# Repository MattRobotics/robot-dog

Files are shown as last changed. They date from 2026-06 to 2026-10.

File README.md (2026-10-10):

# MATDOG — Custom Quadruped Robot

MATDOG is Matt Robotics' custom quadruped platform: a 17-DOF mechanical design with an
articulated head, an ESP32-S3 real-time controller, and a future Jetson-based high-level stack.
This repository is the single active engineering repository for the robot.

> **⚠ FLASH SAFETY NOTICE — 2026-10-08, updated for PR-3. DO NOT FLASH MAIN: do not use `main`
> to update the current robot.**
>
> - `main` carries Calibration Persistence V1, the flash layout `MATDOG_16M_2x5M_NVS_V1` (PR-1),
>   a selective part of the dev.1 line (PR-2) and, since PR-3, the dev.2/dev.3 source delta. Its
>   firmware identity is `0.2.0-dev.3`. `scripts/build.sh` uses `PartitionScheme=custom` and
>   `scripts/upload.sh` refuses every full-image upload.
> - Since 2026-10-10, `main` also has the exact two LED source file blobs of the physically
>   validated, **separate** LED-only firmware `fee9383` (`LED_TRANSPORT=RMT_DMA`); that firmware now
>   runs on the robot. A build of `main` is **not** the installed binary: Git provenance and build
>   ID differ. No flash or motion is authorized.
> - Historical dev.3 Hardware Validation (2026-10-07): execution COMPLETE, acceptance BLOCKED.
>   The later LED-only validation (2026-10-10) passed in its limited scope; **no general release
>   or motion acceptance** is granted.
> - These integrations are **not** a flash authorization and **not** a hardware acceptance. No
>   `main` build has been accepted on hardware.
> - `MOTION_AUTHORIZED=0`, `RESTORE=NOT_IMPLEMENTED`. Nothing here authorizes a flash, a migration
>   or any motion.
>
> Details and sources: [`FLASH_LAYOUT_SAFETY_NOTICE.md`](05_Firmware/MATDOG_Controller/FLASH_LAYOUT_SAFETY_NOTICE.md).
> The quoted snapshot below is the historical state of `main` on 2026-10-01 and has not been
> updated. Elsewhere in this file only the statements on Persistence V1, Wi-Fi/OTA, the motion
> library, the boot census, the thermal verdict and the build identity were updated; a full status
> synchronization is a separate change.

### What is on `main` (after PR-3)

| Layer | Content |
|---|---|
| Code integrated | Persistence V1 and layout V1; post-abort recovery; guarded release stages with DALY supervision; startup RF recovery; Wi-Fi/OTA V3 (TLS, OTA ingest compiled out by default); charging presentation priority; **dev.2 read-only boot servo census**; **dev.3 thermal verdict from direct reads only** and the host runner's one-shot post-abort recovery; identity `0.2.0-dev.3`; pure motion library G1–G5-A, **unwired** (no path to the servo bus) |
| Offline tests | static audit and C++/Python host suites, USB_ONLY and ROBOT_POWERED builds: see [`VALIDATION.md`](05_Firmware/MATDOG_Controller/VALIDATION.md), section PR-3 |
| Hardware results (historical, of the dev.2/dev.3 candidate, not of a `main` build) | 2026-10-06: boot census 13/13; fresh Q0 and calibration 24/24 under dev.3; SAVE/ACK and LOAD across a reset (no real power cycle); the automatic post-abort recovery did not run. Records: [dev.2 audit](09_Logs/Validation_Reports/MATDOG_V0_2_DEV2_BOOT_SELFTEST_DELTA_AUDIT_2026-10-06.md), [dev.3 audit](09_Logs/Validation_Reports/MATDOG_V0_2_DEV3_THERMAL_DELTA_AUDIT_2026-10-06.md). The 2026-10-07 report is not in the repository |
| LED-only hardware validation (2026-10-10) | RMT DMA active on installed `fee9383`; 10-minute ring observation with SoftAP enabled and 0 anomalies; no motor activity ([report](09_Logs/Validation_Reports/MATDOG_LED_RMT_DMA_DIRTY_FRAME_HW_VALIDATION_2026-10-10.md)) |
| Hardware acceptance / release acceptance | LED-only hardware check PASS under tested conditions; dev.3 overall acceptance BLOCKED; no `main` build accepted and no general release approved |
| Deferred | motion execution suites, fresh oracles and the G35/G4/G4.1/G5-A evidence; 38 third-party XGO extracts and XGO-derived data are **not reachable from `main`**; the historical GitHub branches that held them have been deleted, the original commits are in a non-public archive, and removal of previously published blobs from GitHub storage, caches and clones cannot be guaranteed ([ADR-004](09_Logs/Architecture_Decisions/ADR-004_Third-Party_Reverse_Engineering_Material_Boundary.md)) |

> **Historical snapshot — 2026-10-01 (PR #35 merged)**
>
> - **Installed population:** 13 ST3215 (12 leg joints plus neck ID 51); 17 canonical slots,
>   with IDs 52–55 intentionally absent.
> - **Frozen release:** `matdog-controller-v0.1.0`; the separately hardware-validated development
>   firmware is `dfcecb670d05`, `ROBOT_POWERED`.
> - **TRUE Full Calibration HARDWARE-VALIDATED, 2026-10-01:** LF/RF/RH/LH each passed 6/6,
>   all **24/24 contacts** accepted, fine-pass repeatability <= 4 ticks, SAFE_OFF 13/13.
> - **Calibration is RAM-only.** Evidence is exported and backed up; boot-time restoration is
>   not implemented. Operational envelopes are not approved and stand/gait are not authorized.
> - The gait engine remained offline on 2026-10-01. Since PR-2 the pure motion library is on
>   `main`, unwired; its execution suites are deferred.
>
> [2026-10-01 full hardware report](09_Logs/Validation_Reports/Full_Calibration_24_Contact_Hardware_2026-10-01/README.md).

| Track | State |
|---|---|
| `ROBOT_POWERED` no-motion baseline | **VALIDATED** |
| TRUE Full Calibration software and hardware | **24/24 HARDWARE-VALIDATED — 2026-10-01** |
| Calibration Persistence V1 | **IMPLEMENTED on `main` (PR-1, 2026-10-08)** — offline/host-tested; RESTORE not implemented; no hardware acceptance |
| Operational envelopes / JointLimits | **BLOCKED** — not approved |
| Telemetry integrity, LOWER MAX margins, q0 refinement | **OPEN follow-ups** |
| Gait engine | **IN PROGRESS** — pure library on `main` (PR-2), unwired; execution suites and evidence DEFERRED |
| Stand / gait hardware | **BLOCKED** |

The step-by-step route, and what blocks what, is in [`ROADMAP.md`](01_Docs/02_Architecture/ROADMAP.md);
the calibration state in detail is under *Calibration on `main`* below.

## Status vocabulary

Every current-facing document uses these meanings:

| Label | Meaning |
|---|---|
| **VALIDATED** | Implemented and exercised within a stated real-hardware scope. |
| **IMPLEMENTED** | Present in code or hardware, but not yet fully exercised in the relevant hardware scope. |
| **DECIDED** | An approved architecture or policy; implementation may be partial or absent. |
| **TO_TEST** | Implemented or assembled enough for a defined validation step that has not yet passed. |
| **TO_DESIGN** | Direction is known, but the detailed design is not frozen. |
| **FROZEN** | Immutable release, tool, or evidence baseline. |
| **SUPERSEDED** | Replaced as current truth; retained only for traceability. |
| **HISTORICAL** | Accurate evidence of an earlier state, never current authorization. |

## Project status

### VALIDATED

- The 17 allocated ST3215 units completed bench QC/provisioning and hold the frozen
  `MATDOG_C018_V1` persistent profile. This proves the bench campaign, not present installation.
- MATDOG Controller V0.1 boot, native USB CDC, live BNO085 acquisition, viewer-compatible output,
  expected-offline classification, and concurrent soak passed on the real ESP32-S3 under the
  `USB_ONLY` profile.
- Direct ESP32-S3 ownership of the ST3215 bus was demonstrated by the frozen bench tools.
- `ROBOT_POWERED` no-motion operation on the real robot (G3 formal PASS and G3.1 PASS,
  2026-09-18): the hardware profile, the servo population model (canonical 17 / expected-now 13 /
  absent-by-design 52-55) and structured census, live read-only DALY, live LED, two identical
  censuses, `SAFE_OFF` `VERIFIED_OFF` and `torque=0` on all 13, and a Controller loop independent
  of USB CDC host presence. That validation applies to the firmware of that date. The dedicated bounded-calibration
  path subsequently passed its own 24-contact hardware gate on 2026-10-01; operational motion
  has not been validated.
- The post-rewire power gate (2026-09-24): the historical `B-`/`P-` bypass is corrected, and
  physical KEY OFF now measures 0 V on every protected rail with no charger and no USB present.
- LED Status Manager V2 (2026-09-26, source `88062e1`) and the read-only q0 capture on the real
  robot (CR2-C, 2026-09-27, build `315d4ade6ff0`): 12/12 joints, nine samples per joint, Torque
  OFF, maximum spread 0 ticks. It proves the capture path, not calibration.
- The external USB service/programming port (2026-09-24): GPIO19/GPIO20/GND, no host VBUS —
  enumeration, bidirectional CDC and the `esptool` reset/flash-identification handshake all
  confirmed with the onboard USB-C disconnected.
- Manual charging, common-port electrical behaviour (2026-09-22/23 + 2026-09-24): a connected
  charger backfeeds the `B+`/`P-` load bus directly, independent of KEY/Discharge-MOS state. Full
  charging/dock qualification remains **FUTURE**.

- Bounded four-leg calibration passed on hardware on 2026-10-01 (firmware `dfcecb6`):
  24/24 contacts and SAFE_OFF 13/13. This does not validate operational motion.

### IMPLEMENTED

- One modular Controller image contains ServoBus diagnostics, BNO085 acquisition, read-only DALY
  telemetry, LED-ring control, USB diagnostics, health aggregation, and a power-state baseline.
- Wi-Fi/OTA core is implemented and offline-tested; the relevant hardware gates remain open.
- `ActuatorAuthority`, the Safe Actuator policy and the four-leg Full Calibration engine are
  integrated. Only the bounded calibration write path has been hardware-validated; service/QC
  writes and operational stand/gait have not been validated.
- Calibration Persistence V1 (record, A/B store in the dedicated `matdog_nvs` partition,
  SAVE/ACK/RECONCILE, boot LOAD) and the flash layout `MATDOG_16M_2x5M_NVS_V1` are on `main`
  since PR-1 (2026-10-08), offline/host-tested. LOAD never restores a calibration into the
  motion path (`RESTORE` not implemented). Approved operational envelopes are not implemented.

### DECIDED

- MATDOG will use one permanent Controller firmware, extended by reviewed modules rather than
  replaced by separate operational sketches.
- The ESP32-S3 is the sole operational ST3215 bus owner. The high-level host sends semantic intent,
  never raw bus traffic in normal operation.
- Normal future updates will use Wi-Fi/OTA. Native USB CDC/USB-C remains the permanent wired
  service and recovery path.
- GPIO19/GPIO20 mean native USB D-/D+; their historical Jetson-UART use is **SUPERSEDED**.
- The ESP32-S3 is powered from the DALY-protected B+/P− domain through the 5 V step-down. The
  bistable logo pushbutton connects directly to DALY `KEY`; no ESP32 KEY GPIO is required. Its
  function is now a **VALIDATED** power-off (2026-09-24, no charger/USB present) — the fused
  disconnect remains the trusted isolation whenever a charger may be connected, because a
  connected charger backfeeds the load bus independent of KEY state (see *Where we are* below).

### TO_TEST

- Telemetry integrity following 23 isolated temperature outliers and 39 diagnostic held-speed
  transients in the successful hardware run (no confirmed thermal fault or held-role failure).
- LOWER MAX shortfall and reduced repeat-calibration scout margins, particularly RF (+6 ticks)
  and LH (+13 ticks); separate reviewed resolution, no unilateral corridor change.
- BMS KEY configuration persistence across a true DALY power cycle.
- Charging/dock qualification beyond the attended manual session.

### TO_DESIGN

- The host command/telemetry protocol carried over USB CDC.
- Calibration restore across reboot (`RESTORE`), the operational stand/gait workspace with its
  joint limits and margins, and the integrated maintenance, service, Servo QC and provisioning
  workflows.
- Stand and gait motion on hardware, stabilization, ROS 2/MoveIt 2, and complete Jetson
  integration. The pure motion library is on `main` since PR-2 but unwired and not operational;
  its execution suites and evidence are deferred.

### FROZEN, SUPERSEDED, and HISTORICAL

- **FROZEN:** the official Controller tag and the three ST3215 bench tools: Bench QC V6.1, Source
  Signature Survey V1, and Provisioner V6.
- **SUPERSEDED:** mandatory NormaCore Station bus ownership, GPIO19/20 Jetson UART, and Generic V25
  as the current development milestone.
- **HISTORICAL:** dated calibration reports, Geometry/Phase 2A records, old handoffs, and previous
  Station-mediated evidence. They remain preserved and do not describe today's robot.

## Physical hardware today

The allocation registry and the installed population answer different questions:

| Fact | Current value | Canonical source |
|---|---:|---|
| Allocated unit/joint/bus-ID slots | **17** | [`MATDOG_SERVO_ALLOCATION.yaml`](06_Software/Matdog_Core/config/MATDOG_SERVO_ALLOCATION.yaml) |
| Physically installed servos | **13** | This current project snapshot |
| Installed population | 12 leg servos + `NECK_ROTATION` ID 51 | This current project snapshot |
| Allocated but intentionally absent | 52 `NECK_PITCH`, 53 `HEAD_ROTATION`, 54 `HEAD_PITCH`, 55 `JAW` | Allocation registry + this snapshot |

Do not reduce the 17-unit registry to match the current 13-unit build. Allocation is a design/ID
contract; installation is physical state.

```text
ASUS Ubuntu development host / future Jetson Orin Nano Super
    -> native USB 2.0 Full-Speed / USB CDC
MATDOG Controller on ESP32-S3
    -> UART: GPIO17 TX, GPIO18 RX, shared GND
Seeed Bus Servo Driver
    -> Feetech serial bus, 1 Mbps
13 physically installed ST3215 servos
    = 12 legs + NECK_ROTATION ID51
```

All 17 allocated units were bench-provisioned with `PositionOffset = 0`, a servo-level
fact distinct from joint calibration. The current installation passed TRUE Full Calibration
24/24 on 2026-10-01. The 12 fresh q0 values, contacts and diagnostics were exported and
archived. In that session they were RAM-only in the Controller: no automatic restore exists, no
motion is thereby authorized, and no servo EEPROM, ID, `PositionOffset` or NVS write occurred.
Since PR-1 an NVS record store (Calibration Persistence V1) is IMPLEMENTED on `main`. SAVE/ACK and
LOAD across a reset were observed on the dev.3 candidate on 2026-10-06; a real power cycle was not
shown. The runtime state is still held in RAM, automatic `RESTORE` is NOT_IMPLEMENTED, and hardware
acceptance is BLOCKED (dev.3: execution COMPLETE, acceptance BLOCKED).

## Official firmware baseline

| Item | Value |
|---|---|
| Frozen release | `matdog-controller-v0.1.0` |
| Tagged repository commit | `c54862f38a9cbd5e46d6b1770a6d109cc99b5c02` |
| V0.1 USB_ONLY hardware-validated source | `5b371da5482f9b0bd2df1c37ed361250ea54ae8f` |
| Latest hardware-validated development firmware (scope: 2026-10-01 Full Calibration) | `dfcecb670d0565d2db1a8152b6cd7ad230bdb87d` (`ROBOT_POWERED`) |
| Installed candidate (2026-10-06/07) | `0.2.0-dev.3`, provenance `b3fd945bdaf37d192d97b605ac0f59b67f1dba45`; execution COMPLETE, acceptance **BLOCKED**; not an accepted release |
| Full Calibration merge commit on main | `1fd0f5afc3cc737d1ac82183b4ce204dcd01c402` (PR #35; documentation included) |
| Hardware report | [hardware-validation report](09_Logs/Validation_Reports/Full_Calibration_24_Contact_Hardware_2026-10-01/README.md) |

The frozen release, the hardware-flashed source and the later Git merge commit are distinct
identities. The merge commit itself was not flashed.

## Where we are, and the next gate

```text
COMPLETE   Controller V0.1 baseline              VALIDATED (USB_ONLY hardware)
COMPLETE   G2 ROBOT_POWERED software             PASS / FROZEN
COMPLETE   G3 ROBOT_POWERED no-motion            PASS (formal, 2026-09-18)
COMPLETE   G3.1 CDC-independent Controller loop  PASS (2026-09-18)
COMPLETE   DALY KEY research                     COMPLETE (read-only, 2026-09-19)
COMPLETE   DALY 0x81 read                        LIVE VERIFIED (read-only, 2026-09-19)
COMPLETE   DALY KEY write (0x0120 := 0x005A)     LIVE VERIFIED (2026-09-19; ACK + read-back)
                                                 current KEY logic = DISCHARGE (0x005A)
COMPLETE   B-/P- hardware bypass correction      VERIFIED (2026-09-24; TECNOIOT VIN- now on P-)
COMPLETE   post-rewire power gate A-E            PASS (2026-09-24; dead-circuit + KEY OFF/ON +
                                                 powered no-motion regression, live)
COMPLETE   external USB service/programming port VALIDATED (2026-09-24; GPIO19/20, no host VBUS —
                                                 enumeration, CDC, esptool reset/flash-ID)

OPEN       manual charging common-port behaviour VERIFIED electrically (2026-09-22/23 + 09-24):
                                                 a connected charger backfeeds B+/P- regardless
                                                 of KEY state
OPEN       autonomous dock/charging              OPEN — no dock hardware evidence beyond one
                                                 attended manual charging session

COMPLETE   read-only q0 capture              VALIDATED (CR2-C, 2026-09-27)
SUPERSEDED UPPER-only 8-contact milestone      Historical scope error
COMPLETE   TRUE 24-contact calibration         HARDWARE PASS (2026-10-01, PR #35)
CURRENT    Calibration Persistence V1          IMPLEMENTED on main (PR-1); RESTORE not
                                                 implemented; no hardware acceptance
OPEN       Telemetry, LOWER MAX, zero review   Before hardware locomotion
THEN       Operational envelopes / JointLimits BLOCKED pending approval
THEN       Stand / gait hardware               BLOCKED
```

Power domains, KEY semantics, every power state and the charging gates are owned by
[`04_Electronics/MATDOG_POWER_STATES_AND_CHARGING.md`](04_Electronics/MATDOG_POWER_STATES_AND_CHARGING.md).

`ROBOT_POWERED` is **VALIDATED for no-motion operation**: DALY live read-only, LED live, 13/13
expected servos present with 4 absent by design in two identical censuses, `SAFE_OFF`
`VERIFIED_OFF` and `torque=0` on all 13. The Controller loop is independent of USB CDC host
presence: BNO085 acquisition runs at 50.1 Hz with the port closed (G3.1). No commanded servo motion occurred and no robot motion was observed during validation.

### Calibration on `main`

- **Validated scope:** LF V25-derived full-leg state machine, generalized to four legs and 24
  physical contacts (HIP/UPPER/LOWER, MIN/MAX), `HARDWARE_CONTACT_CALIBRATED` 6/6 per leg.
- **Hardware session:** 2026-10-01, firmware `dfcecb6`, `ROBOT_POWERED`, 24/24 witnesses
  accepted on the first attempt and SAFE_OFF 13/13 verified. [hardware-validation report](09_Logs/Validation_Reports/Full_Calibration_24_Contact_Hardware_2026-10-01/README.md).
- **Authority:** session-scoped permits, promoted fresh q0 and the Safe Actuator layer govern
  all bounded calibration writes. No operational actuator authority is implied.
- **Persistence:** in the 2026-10-01 session the promoted calibration was RAM-only and the
  exported data is not an implemented restore. Since PR-1 `main` contains Calibration
  Persistence V1 (SAVE/ACK/LOAD); `RESTORE` is still not implemented.
- **Operational envelope:** not approved (`parameters_approved=0`, `envelope_accepted=0`);
  no stand or gait hardware motion is authorized.
- **Persistence status on `main` (PR-1):**
  - Calibration Persistence V1 **IMPLEMENTED**: SAVE/ACK/RECONCILE and boot LOAD,
    offline/host-tested.
  - `RESTORE` **NOT_IMPLEMENTED**.
  - **No hardware acceptance** for any `main` build.
  - A real power cycle of the persistence path is **not validated**.
- **Follow-ups:** persistence hardware acceptance (including a real power cycle) and
  `RESTORE`; telemetry integrity; LOWER MAX scout margin;
  reviewed mechanical-zero refinement; operational workspace and limits.

### Open hardware notes

- **DALY `KEY` — RESOLVED as a power-off, 2026-09-24.** Research (2026-09-19): no public DALY
  document publishes a K-series KEY register; DALY's own BMSTool V1.14.79 (static inspection)
  points to KEY logic at `0x0120` on a second Modbus personality (`0x81`). Live-verified read-only
  the same day with `@BMS KEY READ`: the unit's KEY logic was **DISABLED (`0x0055`)**
  pre-commissioning, consistent with the G3 finding, where toggling the physical KEY produced no
  observed change in `discharge_mos`. The single guarded write (`@BMS KEY SET DISCHARGE CONFIRM`,
  `0x0120 := 0x005A`) was sent **once, live, on 2026-09-19** and read back as `0x005A`
  (DISCHARGE). The follow-on physical KEY test was inconclusive at the time: a hardware `B-`/`P-`
  bypass (TECNOIOT `VIN-` on raw `B-`) kept the load rail powered with the discharge MOS open. That
  rewire is now **complete**, and the post-rewire power gate A–E **passed live on 2026-09-24**:
  with no charger and no USB present, KEY OFF measures 0 V on every protected rail. A connected
  charger still backfeeds the `B+`/`P-` bus independent of KEY state, so the fused disconnect
  remains the trusted physical isolation method whenever a charger may be present.
- **GPIO19/GPIO20 — VALIDATED 2026-09-24.** GPIO19 = native USB D−, GPIO20 = native USB D+. The
  external 19/20/GND connector (host VBUS intentionally not wired) was validated as a
  service/programming port: native enumeration, bidirectional CDC and the `esptool`
  reset/flash-identification handshake all confirmed with the onboard USB-C disconnected. It does
  not power the ESP32 on its own.

Criteria are owned by the Controller
[`DEVELOPMENT_GATES.md`](05_Firmware/MATDOG_Controller/DEVELOPMENT_GATES.md); evidence by the
Controller [`VALIDATION.md`](05_Firmware/MATDOG_Controller/VALIDATION.md).

### Everything after that

The full development sequence, its hard dependencies and what is blocked by what are owned by
[`ROADMAP.md`](01_Docs/02_Architecture/ROADMAP.md). Per-gate entry conditions and pass/fail
criteria are owned by
[`DEVELOPMENT_GATES.md`](05_Firmware/MATDOG_Controller/DEVELOPMENT_GATES.md). They are
deliberately not duplicated here.

## Target architecture

The permanent MATDOG Controller is the integration point for future Diagnostics, Maintenance,
Service, Servo QC, Provisioning, Full Leg Calibration, Wi-Fi/OTA, and host transport. Calibration
motion is implemented behind the Safe Actuator layer; stand, IK, gait, and stabilization come
later, behind explicit safety and calibration gates.

**DECIDED (2026-09-16):** MATDOG will also host a permanent **Embedded Web UI / Control & Service
Dashboard** served by the ESP32-S3 and reached from a phone, tablet, the ASUS or a future Jetson.
It is a staged, safety-gated target and none of it exists in firmware yet. Every browser command
must travel `Browser -> CommandRouter -> Controller services -> authority -> Safe Actuator ->
ServoBus`; a direct browser-to-`ServoBus` path is permanently forbidden. Contract in
[`ARCHITECTURE.md`](01_Docs/02_Architecture/ARCHITECTURE.md#embedded-matdog-web-ui--control--service-dashboard).

The Full Leg Calibrator V1 tree is a preserved oracle/evidence source, held by the annotated tag
`archive/2026-08-29/full-leg-calibrator-v1-h0` -> `15f3fb8f378e6cadf6bc479bfcaca2947741c9fd` (the
former branch `matdog/full-leg-calibrator-v1` was archived 2026-09-18 and no longer exists). Its
useful calibration engine, safety, and evidence patterns may later be migrated selectively into
the Controller; it is not the final runtime architecture and must not be merged wholesale.

The frozen ST3215 tools remain immutable qualification evidence even after equivalent service
capabilities are integrated into the Controller.

## Canonical documentation

| Question | Canonical owner |
|---|---|
| What exists and what happens next? | This `README.md` |
| What are the architecture contracts and target direction? | [`ARCHITECTURE.md`](01_Docs/02_Architecture/ARCHITECTURE.md) |
| What is the development sequence, and what blocks what? | [`ROADMAP.md`](01_Docs/02_Architecture/ROADMAP.md) |
| What must be true before a stage may begin? | [`DEVELOPMENT_GATES.md`](05_Firmware/MATDOG_Controller/DEVELOPMENT_GATES.md) |
| How are power, wiring, and connectors implemented? | [`04_Electronics/README.md`](04_Electronics/README.md) |
| What firmware exists? | [`05_Firmware/README.md`](05_Firmware/README.md) |
| May `main` be flashed on the current robot? | [`FLASH_LAYOUT_SAFETY_NOTICE.md`](05_Firmware/MATDOG_Controller/FLASH_LAYOUT_SAFETY_NOTICE.md) — **no** |
| What is the Controller baseline and service model? | [Controller README](05_Firmware/MATDOG_Controller/README.md) |
| What Controller behavior was actually validated? | [Controller validation](05_Firmware/MATDOG_Controller/VALIDATION.md) |
| Which 17 units/joints/IDs are allocated? | [`MATDOG_SERVO_ALLOCATION.yaml`](06_Software/Matdog_Core/config/MATDOG_SERVO_ALLOCATION.yaml) |
| Is calibration commandable? | [`MATDOG_JOINT_CALIBRATION.yaml`](06_Software/Matdog_Core/calibration/MATDOG_JOINT_CALIBRATION.yaml) |
| Where is frozen ST3215 evidence? | [`ST3215_EVIDENCE_INDEX.md`](09_Logs/ST3215_EVIDENCE_INDEX.md) |
| Where is superseded/historical material? | [`09_Logs/Historical/`](09_Logs/Historical/README.md) |
| How did the project get here (June–October 2026)? | [`HISTORY_INDEX.md`](09_Logs/HISTORY_INDEX.md) |
| Which decisions were taken, and which are superseded? | [ADR index](09_Logs/Architecture_Decisions/README.md) |
| Which development logs and validation reports exist? | [Development Log index](09_Logs/Development_Log/README.md), [Validation Reports index](09_Logs/Validation_Reports/README.md) |
| What is still open or missing? | [`OPEN_ITEMS.md`](09_Logs/OPEN_ITEMS.md) |
| Where do original commit SHAs map after the selective integrations? | [`COMMIT_PROVENANCE_MAP.md`](09_Logs/COMMIT_PROVENANCE_MAP.md); archives held outside GitHub: [`EXTERNAL_ARCHIVES.md`](09_Logs/EXTERNAL_ARCHIVES.md) |
| Where is Geometry Compiler verification evidence? | [`REPOSITORY_VERIFICATION_INDEX.md`](REPOSITORY_VERIFICATION_INDEX.md) (**HISTORICAL/REFERENCE**, not project status) |

## Repository layout

```text
01_Docs/        architecture and stable technical references
02_BOM/         components, suppliers, and costs
03_CAD/         CAD, URDF, meshes, and mechanical exports
04_Electronics/ wiring, power, and servo-mapping references
05_Firmware/    permanent Controller plus frozen bench tools
06_Software/    calibration, geometry, kinematics, and host-side software
07_Media/       images, renders, and videos
08_Tests/       repeatable validation procedures
09_Logs/        evidence, decisions, reports, and historical archives (start at HISTORY_INDEX.md)
09_Backups/     manifests and receipts of encrypted flash backups (no plaintext images)
```

## Safety boundary

- No motion from stale or un-restored calibration. The 2026-10-01 contact validation
  does not authorize stand, gait or load-bearing operation. Any new hardware calibration
  or motion session requires separate operator authorization.
- No servo EEPROM/ID change or hardware reflash is authorized by this documentation. In
  particular, never flash a `main` build onto the current robot (see the flash safety notice
  at the top of this file).
- `PositionOffset = 0` is the persistent baseline; mechanical mounting errors are corrected
  mechanically, not hidden in EEPROM.
- Frozen tools and historical evidence are never edited to make them appear current.
- `UNRESOLVED != PASS`, `DIAGNOSTIC != EXECUTABLE`, and geometric contact is not motion
  authorization.

Built and documented by Matt Robotics.

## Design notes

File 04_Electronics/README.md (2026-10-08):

# MATDOG Electronics

Electrical architecture and hardware integration records for MATDOG.

Canonical system architecture: [`01_Docs/02_Architecture/ARCHITECTURE.md`](../01_Docs/02_Architecture/ARCHITECTURE.md)

Canonical power domains, `KEY`/Charge-MOS semantics, power states, daily use, service isolation and
charging: [`MATDOG_POWER_STATES_AND_CHARGING.md`](MATDOG_POWER_STATES_AND_CHARGING.md)

Canonical current project snapshot, including the physically installed population:
[`README.md`](../README.md)

---

## Current control chain

```text
high-level host
  ASUS Ubuntu (development)  /  Jetson Orin Nano Super (final onboard)
        ↓  native USB 2.0 Full-Speed / USB CDC
        ↓  ESP32-S3 D− = GPIO19, D+ = GPIO20
ESP32-S3 MATDOG Controller           ← owns the ST3215 protocol and control
        ↓  UART
        ↓  GPIO17 TX → driver RX
        ↓  GPIO18 RX ← driver TX
        ↓  shared GND
Seeed Bus Servo Driver               ← servo-bus electrical layer
        ↓  Feetech serial bus, 1 Mbps
        ↓  custom power-distribution busbar
13 × Feetech ST-3215-C018 installed  12 leg + NECK_ROTATION ID51
```

The GPIO17/GPIO18 UART assignment is not aspirational — it is compiled into the frozen bench
firmware (`SERVO_TX_PIN = 17`, `SERVO_RX_PIN = 18`) that provisioned all 17 servos.
Provisioning/allocation history is not the same as physical installation: the canonical registry
allocates 17 units, but only 13 are installed today.

### Host link

| Property | Value |
|---|---|
| Transport | native USB 2.0 Full-Speed / USB CDC — **DECIDED**; validated through the controller's native USB connection |
| ESP32-S3 USB pins | D− = **GPIO19**, D+ = **GPIO20** |
| External 4-pin connector | GPIO19, GPIO20, ESP32 GND; 5 V is **not connected** — **VALIDATED** 2026-09-24 as a USB service/programming port (enumeration, CDC, `esptool` reset/flash-ID); does not power the ESP32 on its own |
| Theoretical rate | 12 Mbit/s |
| USB 3.x | neither required nor available on ESP32-S3 |
| Secondary channel | Wi-Fi command/diagnostic — planned |
| Packet/command protocol | **TBD** — transport frozen, protocol is not |

Historical Jetson-UART use of GPIO19/GPIO20 is **SUPERSEDED**. Their current canonical meaning is
native USB D−/D+. The external connector (GPIO19, GPIO20, GND; host VBUS intentionally not wired)
was validated 2026-09-24 as a USB service/programming link: native enumeration, bidirectional CDC,
and the `esptool` reset/flash-identification handshake all confirmed with the onboard USB-C
disconnected, and the board re-enumerated correctly after `esptool`'s hard reset. Because host
VBUS is not connected, this port cannot power the ESP32 on its own — diagnostics/programming
through it require the robot already powered from its protected supply (normally KEY ON).

### M0.2 assembled service configuration — 2026-10-02

For the real M0 Gate A, power was battery through DALY with KEY ON: servo/LED
rails stayed live and TECNOIOT supplied the ESP32-S3 with 5 V. The host used only
the external GPIO19/D−, GPIO20/D+, GND service port, without VBUS; the onboard
USB-C was not used. BOOT and EN are under the cover and unavailable while
assembled. All 13 servos were reported torque=0, speed=0, current=0 before ROM
entry; the robot was mechanically supported with legs free and the breaker
accessible. This observation does not certify servo state after a power cycle.

ROM entry with esptool 5.3.1 `--before usb-reset --after no-reset --no-stub
--connect-attempts 1` was verified against the working legacy application;
subsequent reads used `no-reset`. Two full backups are verified. Recovery after
an interrupted app/table write or power loss has **not** been demonstrated with
BOOT/EN inaccessible: migration Gate B remains **BLOCKED**. USB-C-only power
with isolated rails is a different future configuration, not the standard for
this assembled installation. No electrical redesign is part of M0.2. See the
[current migration runbook](../05_Firmware/MATDOG_Controller/FLASH_LAYOUT_M0_RUNBOOK.md)
and [M0.2 report](../09_Logs/Development_Log/2026-10-02_M0_2_HARDWARE_ALIGNMENT.md).

---

## Current hardware decisions

Lean by design. Each item below is a deliberate decision, not an omission.

| Decision | Status |
|---|---|
| **Seeed Bus Servo Driver** for the servo-bus electrical layer | selected |
| **No CAN transceiver** | decided — not part of the current architecture |
| **ESP32-S3 power**: DALY-protected B+/P− domain → TECNOIOT 5 V step-down | **DECIDED**; validated no-motion in ROBOT_POWERED (G3, 2026-09-18). The ESP32 is **not** a raw-`B−` always-on load and needs **no isolated DC/DC**. **Hardware correction completed and validated 2026-09-24**: TECNOIOT `VIN−` now returns to `P−`, not `B−` (see Power-domain invariant below) |
| **Power-domain invariant**: battery `B−` → DALY `B−` only; every ordinary load returns to `P−` | **DECIDED**; physical conformance **VERIFIED** 2026-09-24 (post-rewire power gate A–E, PASS) |
| **Primary hardware ON/OFF/wake**: bistable pushbutton under the robot logo → DALY `KEY` directly | **DECIDED**; no ESP32 GPIO required. KEY logic read live 2026-09-19 as **DISABLED** (`0x0055`), which explained the G3 finding, then set **once** to **DISCHARGE** (`0x005A`) by the guarded write — acknowledged and read back. KEY now controls the **discharge MOS only**; the charge MOS stays normally ON and must never be mapped to KEY. Physical KEY OFF/ON behaviour is **VERIFIED** 2026-09-24 (post-rewire power gate A–E, PASS) with no charger and no USB present. A connected charger still backfeeds the `B+`/`P−` bus independent of KEY state — see `MATDOG_POWER_STATES_AND_CHARGING.md` § 8 |
| **One removable, externally accessible ATO main fuse** | decided — rating **TBD** |
| **Custom motor power busbar** | decided — dimensions and material **TBD** |
| **Locking 3D-printed cable housings** | decided |
| **No bulk servo capacitor** initially | decided — may be revisited after load measurement |
| **No TVS** initially | decided — may be revisited after load measurement |

> Values marked **TBD** are genuinely not frozen. They are deliberately not invented here.

### Deferred, with the reason

The bulk capacitor and TVS are omitted **initially**, not permanently. Both depend on real
transient behaviour under load, which cannot be measured until the robot is reassembled,
recalibrated and drawing current across the installed servo population. Revisit after the current
13-servo system is measured; repeat the budget if the population later expands toward all 17
allocated joints.

---

## Power and wiring — validation status

The power architecture is **DECIDED**, and the installed 13-servo configuration **passed
ROBOT_POWERED no-motion validation** (G3 formal PASS 2026-09-17/18, G3.1 PASS 2026-09-18: DALY
live read-only, LED live, 13/13 expected servos with 4 absent by design in two identical censuses,
`VERIFIED_OFF` and `torque=0` on all 13). That evidence covers a *powered, no-motion* robot only.

**VERIFIED** 2026-09-24: power-domain conformance after the `TECNOIOT VIN−` → `P−` rewire, and KEY
OFF actually removing the robot rails with no charger/USB present (post-rewire power gate A–E,
PASS — see `MATDOG_POWER_STATES_AND_CHARGING.md` § 11).

Still **TO_TEST**:

- the final busbar / power-distribution items G3 did not cover (busbar build, ATO rating, installed
  13-servo wiring);
- sustained multi-servo power/load behaviour — no motion or multi-servo load test exists.

### VALIDATED — proven on real hardware

- **ESP32-S3 direct ST3215 bus operation** — the ESP32-S3 exclusively owned and drove the bus.
- **Direct bus-control path**, to the extent covered by real bring-up evidence.
- **QC and provisioning** — 26 QC runs and 17/17 units provisioned.

Evidence: [Bench QC V6.1](../09_Logs/Validation_Reports/ST3215_Bench_QC_2026-08-24/README.md) ·
[provisioning campaign](../09_Logs/Validation_Reports/ST3215_Provisioning_2026-08-27/README.md).

> That evidence is **bench** evidence: single-unit bench rig, one servo at a time. It says nothing
> about the assembled 13-servo power system.

### TO_TEST — not yet final-hardware-validated

- the custom final **busbar / power distribution**;
- the **ATO protection implementation** (rating TBD);
- the installed **13-servo wiring**;
- the installed **13-servo power budget** and any later 17-unit expansion;
- the **charging path** beyond the one attended manual session (charger CC/CV was confirmed
  live 2026-09-22/23; dock/contacts, negative return under autonomous docking, reverse polarity,
  and thermal/current behaviour under longer sessions remain untested) — see
  [`MATDOG_POWER_STATES_AND_CHARGING.md`](MATDOG_POWER_STATES_AND_CHARGING.md) § 8;
- BMS KEY-configuration persistence across a true DALY power cycle (only KEY toggles and
  fuse removal/reinsertion have been tested, not a BMS power cycle).

**VERIFIED** 2026-09-24: the DALY `KEY` power/wake/shutdown function on the rails (BMS-side
configuration `0x005A` DISCHARGE, and the physical KEY test — the `B−`/`P−` bypass is corrected and
the post-rewire procedure passed) and the GPIO19/GPIO20 external USB-data/service connector (native
enumeration, CDC, `esptool` reset/flash-ID). The fused disconnect remains the trusted maintenance
isolation point whenever a charger may be connected — see
[`MATDOG_POWER_STATES_AND_CHARGING.md`](MATDOG_POWER_STATES_AND_CHARGING.md) §§ 7–8.

Protection is deliberately minimal in the current revision: one externally accessible ATO main
fuse, removable without disassembly.

> **The existing 3S power-load analysis was written for 12 servos.** There are now 13 physically
> installed, while the canonical allocation reserves 17. The load budget must be re-evaluated
> before sustained multi-servo motion — see
> [`01_Docs/01_Analysis/ST3215_Quadruped_3S_Power_Load_Analysis.md`](../01_Docs/01_Analysis/ST3215_Quadruped_3S_Power_Load_Analysis.md).

### Historical

The earlier custom distribution board and branch wiring were validated for the **12-servo**
Station-mediated development phase. That validation belongs to a configuration the robot no longer
has, and does not carry over to today's 13-servo installation or a future 17-unit installation.

---

## Allocation versus installed population

Authoritative machine-readable source:
[`06_Software/Matdog_Core/config/MATDOG_SERVO_ALLOCATION.yaml`](../06_Software/Matdog_Core/config/MATDOG_SERVO_ALLOCATION.yaml)

```text
canonical allocation: 17 units / IDs
installed today:      13 = 12 leg servos + NECK_ROTATION ID51
absent by design:      4 = 52 NECK_PITCH, 53 HEAD_ROTATION,
                           54 HEAD_PITCH, 55 JAW
```

Do not reduce the 17-unit allocation registry to match the current 13-unit installation. Fourteen
of the 17 allocated units were recoded during provisioning, so older records keyed only by bus ID
may associate the wrong joint. The root README owns the current installed-population snapshot; the
allocation YAML owns the complete unit → joint → ID registry.

## Contents

- `Servo_Mapping/` — legacy 12-leg mapping/reference; it is not the canonical 17-unit allocation
  registry or a statement of today's installed population.

## Future contents

- wiring diagrams
- power-distribution-board documentation
- battery and BMS design
- charging and docking system
- IMU integration
- head sensors
- Jetson Orin Nano Super integration
- electrical validation measurements

---

## Historical

The **Waveshare Bus Servo Adapter** was the bench/development interface during the
Station-mediated phase and appears in evidence from that period, including the 2026-06-17 ST3215
bus validation. It is **not** the selected production interface — the current chain uses the Seeed
Bus Servo Driver.

Raw ST3215 bus diagnostics are provided by the ESP32-S3 bench tools
([`05_Firmware/ST3215_Bench_Tools/`](../05_Firmware/ST3215_Bench_Tools/README.md)). NormaCore
Station is optional/legacy tooling and is not required for any MATDOG bus operation.

→ [Historical index](../09_Logs/Historical/README.md)

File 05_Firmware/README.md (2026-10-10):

# MATDOG Firmware

This directory is reserved for low-level firmware that belongs specifically to MATDOG.

> **⚠ Flash safety — 2026-10-08, updated for PR-3.** Do not build from or flash `main` to update
> the current robot.
> - `main` uses the robot's layout `MATDOG_16M_2x5M_NVS_V1`, carries Calibration Persistence V1,
>   a selective part of the dev.1 line and the dev.2/dev.3 source delta (identity `0.2.0-dev.3`).
> - On 2026-10-10 the installed **LED-only** firmware was upgraded to local commit `fee9383`;
>   `main` now includes its exact two LED source blobs, but a build of `main` is not that installed
>   image. Historical dev.3 overall acceptance remains BLOCKED; no general release or flash is approved.
>
> See [`MATDOG_Controller/FLASH_LAYOUT_SAFETY_NOTICE.md`](MATDOG_Controller/FLASH_LAYOUT_SAFETY_NOTICE.md).

## Current status

**Bench firmware exists and is frozen.** [`ST3215_Bench_Tools/`](ST3215_Bench_Tools/) holds three
ESP32-S3 tools that have run on real hardware and are archived byte-for-byte:

| Tool | Purpose | Status |
|---|---|---|
| [Bench QC V6.1](ST3215_Bench_Tools/Bench_QC_V6_1/) | servo quality audit | frozen — 26 runs PASS |
| [Source Signature Survey V1](ST3215_Bench_Tools/Source_Signature_Survey_V1/) | read-only 71-byte state capture | frozen |
| [Provisioner V6](ST3215_Bench_Tools/Provisioner_V6/) | apply `MATDOG_C018_V1`, centre, zero offset, recode ID | frozen — 17/17 PASS |

These are **bench** tools: they run on a bench rig with a single servo attached, never on the
assembled robot under power for motion.

**Controller V0.1 is the frozen release baseline.** The current development Controller
passed TRUE Full Calibration 24/24 on real hardware on 2026-10-01 (build `dfcecb670d05`).
[`MATDOG_Controller/`](MATDOG_Controller/) is the first unified operational ESP32-S3 firmware:
one deployable image with modular ServoBus / BNO085 / DALY BMS / LED ring / USB diagnostics,
adapted from the hardware-proven bench and bring-up sources above rather than rewritten from
scratch. USB-only bench validation (boot, BNO085 live acquisition, existing viewer compatibility,
expected-offline classification for DALY/ST3215/LED) is recorded in
[`MATDOG_Controller/VALIDATION.md`](MATDOG_Controller/VALIDATION.md). **Operational stand/gait motion and operational IK remain unimplemented** — V0.1 is an integration and platform milestone, not a
motion controller.

The official tagged baseline and exact validated source are recorded in the
[`MATDOG_Controller` README](MATDOG_Controller/README.md#official-baseline). The root
[`README.md`](../README.md) owns the current project and hardware snapshot; the Controller
[`VALIDATION.md`](MATDOG_Controller/VALIDATION.md#present-day-baseline-and-next-gate) owns the
detailed validation status and next gate. This page is the firmware-area index.

The current hardware/control chain is:

    ASUS Ubuntu (dev) / Jetson Orin Nano Super (final)
    → native USB 2.0 Full-Speed / USB CDC
    → ESP32-S3 MATDOG Controller         ← owns the ST3215 bus
    → UART GPIO17/GPIO18
    → Seeed Bus Servo Driver
    → 13 installed ST3215 servos        12 legs + NECK_ROTATION ID51

The ESP32-S3 is the operational owner of the servo serial bus.

The canonical allocation still contains 17 units. IDs 52–55 are allocated but intentionally
absent today; allocation and installation must not be conflated.

## Permanent Controller direction

The architectural direction is **one permanent `MATDOG_Controller` firmware**, extended in reviewed
stages rather than replaced by standalone operational images. It already implements IMU
acquisition, read-only battery telemetry, a USB diagnostic surface and a power-state-machine
baseline. Future integrated capabilities include:

- diagnostics, maintenance and service modes
- servo QC and provisioning
- calibration persistence and approved operational envelopes
- Wi-Fi / OTA and host transport
- deterministic servo motion / operational IK / gait execution
- closed-loop BNO085 stabilization
- watchdog / safety interlocks beyond the current health aggregation
- verified DALY write support (Discharge MOS OFF), once the K-Series protocol is identified
- Jetson onboard host integration

The Full Leg Calibrator V1 tree is preserved as an implementation and evidence oracle by the
annotated tag `archive/2026-08-29/full-leg-calibrator-v1-h0` ->
`15f3fb8f378e6cadf6bc479bfcaca2947741c9fd`; the former branch `matdog/full-leg-calibrator-v1` was
archived 2026-09-18 and no longer exists. It is not the final runtime architecture and must not be
merged wholesale; the current Controller already reuses reviewed V25 calibration patterns.

The frozen ST3215 tools remain immutable qualification evidence. Equivalent service capabilities
may later be integrated into the Controller without rewriting or replacing those frozen sources.

## Architecture Rule

Do not add experimental host-side gait, IK or calibration code directly to this firmware area;
host-side development belongs under `06_Software/`.

Bench firmware **is** in scope for this directory — it is genuine low-level ST3215 firmware.
Anything added here must follow the freeze policy in
[`ST3215_Bench_Tools/README.md`](ST3215_Bench_Tools/README.md): byte-for-byte source, SHA256 for
every artifact, provenance, complete command surface, toolchain/FQBN, test result, hardware
validation scope, and an explicit statement of what is **not** validated.

**Operational stand/gait execution and operational IK are planned for the ESP32-S3,
but are not yet hardware-authorized.** Bounded calibration motion passed its own hardware gate. IMU acquisition, read-only power telemetry and a USB
diagnostic/health surface **are** written, as of `MATDOG_Controller` V0.1 — see
[`MATDOG_Controller/VALIDATION.md`](MATDOG_Controller/VALIDATION.md) for exactly what has been
exercised on real hardware versus what remains software-only. `MATDOG_Controller` is distinct
from the frozen bench tools above, which remain qualification instruments rather than robot
runtime.

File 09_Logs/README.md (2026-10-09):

# MATDOG logs and evidence

> **CHRONOLOGY AND EVIDENCE — NOT CURRENT-STATE AUTHORITY**
>
> Start with the [root README](../README.md) for today's hardware, firmware baseline, validation
> status and immediate milestone. Active architecture contracts live in
> [ARCHITECTURE.md](../01_Docs/02_Architecture/ARCHITECTURE.md).

This directory preserves dated engineering decisions, development chronology, calibration records
and validation evidence. A result remains evidence for its recorded date and scope; it does not
automatically describe the robot after a later rebuild or architecture change.

## Navigation

| Area | Purpose |
|---|---|
| [History index](HISTORY_INDEX.md) | One chronology, June–October 2026: phases, status, documents and available evidence |
| [Open items](OPEN_ITEMS.md) | Blockers and residuals; checkpoint after PR #40 (2026-10-08), updated after PR #41 and for C2 (2026-10-09) |
| [Commit provenance map](COMMIT_PROVENANCE_MAP.md) | PR #37–#41 merge SHAs; original SHA to recreated SHA for PR-2 and PR-3 (PR #38 merged with original SHAs; PR #41 is documentation only) |
| [External archives](EXTERNAL_ARCHIVES.md) | Deleted branches (last tips), remaining tags, the non-public archive status and recovery steps; items without evidence stay `EXTERNAL_ARCHIVE_PENDING_VERIFICATION` |
| [ST3215 evidence index](ST3215_EVIDENCE_INDEX.md) | Canonical navigation for bench QC, source survey, provisioning and frozen-tool evidence |
| [`Validation_Reports/`](Validation_Reports/README.md) | Dated hardware, software and model validation evidence; each claim is limited to its stated scope |
| [`Calibration/`](Calibration/) | Calibration records and the 2026-08-27 reset notice; pre-reset values are historical |
| [`Calibration_Sessions/`](Calibration_Sessions/) | Raw and derived records from dated calibration sessions |
| [`Development_Log/`](Development_Log/README.md) | Chronological handoffs and milestone records; their “next steps” are historical |
| [`Architecture_Decisions/`](Architecture_Decisions/README.md) | Dated ADRs; consult the canonical architecture before treating an older decision as active |
| [Historical index](Historical/README.md) | Explicitly superseded material and preserved engineering archives |

## Reading rules

- Validation means only that the documented test passed within its recorded scope.
- A dated handoff records what was current then; it does not own today's milestone.
- ST3215 provisioning of 17 allocated units is not a statement that 17 servos are physically
  installed today.
- Historical calibration and archived tools provide evidence or engineering reference, never
  hardware-motion authorization.
- Keep evidence at its existing path so hashes, manifests and inbound links remain intact.

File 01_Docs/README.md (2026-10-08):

# MATDOG Documentation

This directory contains stable engineering documentation and technical references.

## Contents

- architecture documents
- calibration procedures
- kinematic conventions
- upstream integration contracts
- technical research
- design standards

## Project History

Chronological engineering history does not belong here.

Use [09_Logs](../09_Logs/) for:

- architecture decisions
- validation reports
- development milestones
- test conclusions

## Where to start

| For | Read |
|---|---|
| Current state and standing limits | [Root README](../README.md) |
| Permanent contracts and boundaries | [`ARCHITECTURE.md`](02_Architecture/ARCHITECTURE.md) |
| Staged plan | [`ROADMAP.md`](02_Architecture/ROADMAP.md) |
| Gate criteria and evidence for the Controller | [`DEVELOPMENT_GATES.md`](../05_Firmware/MATDOG_Controller/DEVELOPMENT_GATES.md), [`VALIDATION.md`](../05_Firmware/MATDOG_Controller/VALIDATION.md) |
| Chronology, June–October 2026 | [`HISTORY_INDEX.md`](../09_Logs/HISTORY_INDEX.md) |
| Decisions | [ADR index](../09_Logs/Architecture_Decisions/README.md) |
| Blockers | [`OPEN_ITEMS.md`](../09_Logs/OPEN_ITEMS.md) |

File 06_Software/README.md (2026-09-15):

# MATDOG Software

This area contains MATDOG-specific host-side tools, machine-readable configuration, offline
geometry and kinematics code, validation utilities, and visualization software.

It does not own the current project milestone or the robot's runtime architecture:

| Need | Canonical owner |
|---|---|
| Current project snapshot and immediate milestone | [Root `README.md`](../README.md) |
| Runtime architecture and responsibility boundaries | [`ARCHITECTURE.md`](../01_Docs/02_Architecture/ARCHITECTURE.md) |
| Operational ESP32-S3 firmware | [MATDOG Controller](../05_Firmware/MATDOG_Controller/README.md) |

## Contents

- [`Matdog_Core/config/`](Matdog_Core/config/) — machine-readable allocation, servo-profile, and
  geometry configuration.
- [`Matdog_Core/calibration/`](Matdog_Core/calibration/) — calibration data contracts, offline
  geometry tooling, validators, and preserved calibration-development records.
- [`Matdog_Core/kinematics/`](Matdog_Core/kinematics/) — kinematic models, offline safety policies,
  and associated tests.
- [`Matdog_Core/hardware/`](Matdog_Core/hardware/) — retained hardware-facing development tools;
  they are not current motion authorization.
- [`Matdog_Core/viewer/`](Matdog_Core/viewer/) — host-side visualization tools.

## Current boundary

The permanent operational actuator boundary is the ESP32-S3 MATDOG Controller. New host-side
software may express semantic robot intent, but it must not become an independent owner of the
ST3215 serial bus or redefine Controller responsibilities. The host protocol carried over the
selected transport remains an architecture-level contract.

The calibration directory deliberately contains both reusable offline engineering work and dated
Station-era procedures, handoffs, and evidence. A historical document remains evidence for its
recorded phase; it is not current runtime, current calibration, a current milestone, or permission
to operate hardware. Follow each file's status banner and the
[historical index](../09_Logs/Historical/README.md).

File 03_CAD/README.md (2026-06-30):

# MATDOG — CAD and Robot Description

This directory contains the mechanical representation of MATDOG.

## Scope

- Solid Edge master CAD exports
- URDF robot descriptions
- STL visual meshes
- STL collision meshes
- Mechanical reference data
- Kinematic reference workbooks

## Current Canonical Package

The first complete robot description is:

[MATDOG URDF REV00](URDF/matt_robodog_rev00/)

REV00 contains the validated 17-link and 16-joint kinematic baseline used for:

- joint calibration
- forward kinematics
- inverse kinematics
- stand-pose development
- gait development
- future simulation

## Organisation

03_CAD/
├── README.md
└── URDF/
    ├── README.md
    └── matt_robodog_rev00/

The Solid Edge CAD assemblies remain the geometric source of truth.

The URDF is the canonical kinematic description derived from the CAD master.

Any canonical change to joint origins, axes, limits, mesh orientation or foot-contact frames must update both the URDF package and its kinematic reference workbook.

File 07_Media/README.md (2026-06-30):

# MATDOG Media

This directory contains media created specifically for the MATDOG project.

## Scope

- photographs of assemblies and prototypes
- CAD renders
- URDF and simulation screenshots
- calibration photographs
- test videos
- locomotion demonstrations
- public project graphics
- media assets used for documentation

## Organisation Rule

Engineering evidence should remain close to the related technical record when practical.

Examples:

- a servo-bus validation video may be referenced from 09_Logs/Validation_Reports/
- a calibration photograph may be referenced from its calibration procedure
- a public render or project image belongs here

Large raw video files should not be committed to Git unless they are essential engineering evidence.

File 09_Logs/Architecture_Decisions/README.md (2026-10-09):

# Architecture decisions — index

Dated decision records. Each ADR keeps the text it had when it was written; later status changes
are added as annotations, never by rewriting the original decision.
Current architecture: [`ARCHITECTURE.md`](../../01_Docs/02_Architecture/ARCHITECTURE.md).
Chronology: [`HISTORY_INDEX.md`](../HISTORY_INDEX.md).

| ADR | Date | Subject | Status today | Note |
|---|---|---|---|---|
| [ADR-001](ADR-001_Quadruped_Control_Architecture.md) | 2026-06 | Quadruped control architecture: NormaCore Station as sole ST3215 bus owner, Waveshare adapter, 12 servos | **SUPERSEDED** (banner dated 2026-08-27) | Replaced by the ESP32-S3 Controller as operational bus owner, with 17 allocated servo slots (13 physically installed today: 12 leg + neck ID 51). Preserved as the historical decision. |
| [ADR-002](ADR-002_MATDOG_Repository_and_Station_Integration.md) | 2026-06-25 | `robot-dog` is the MATDOG reference repository; boundary with NormaCore Station | **Accepted, partially superseded** (annotation 2026-10-08) | Still valid: `robot-dog` is the source of truth for MATDOG. Superseded: direct servo-bus control by NormaCore Station. See the "Status update" section of the ADR. |
| [ADR-003](ADR-003_URDF_REV00_Kinematic_Baseline.md) | 2026-06-30 | URDF REV00 kinematic baseline | **Accepted** | Canonical robot description used by geometry, kinematics and motion code. |
| [ADR-004](ADR-004_Third-Party_Reverse_Engineering_Material_Boundary.md) | 2026-10-08 | Third-party reverse-engineering material stays out of MATDOG history | **Accepted** (annotation 2026-10-09: branches deleted, exposure not guaranteed removed) | Boundary applied by PR #39 and PR #40. Deferred material is recorded by path and SHA-256 only. Not to be weakened without a separate owner decision. |

Related dated decisions kept outside the ADR series:

- [Calibration reset, 2026-08-27](../Calibration/MATDOG_CALIBRATION_RESET_2026-08-27.md) — all
  calibration recorded before the physical rebuild is historical.
- [Historical index](../Historical/README.md) — the three events (Station to ESP32-S3, 12 servos to
  17 allocated slots, hardware decisions frozen).

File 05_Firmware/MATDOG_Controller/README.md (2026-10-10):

# MATDOG Controller

The first unified operational ESP32-S3 runtime for MATDOG. It replaces the previous
one-sketch-per-peripheral workflow (ST3215 bench tools, BNO085 Phase C3, DALY probes)
with one modular, deployable firmware image that initializes each subsystem module
together and reports whether its hardware is detected, expected or unavailable.

> **⚠ Flash safety — 2026-10-08, updated for PR-3.** This tree uses the flash layout
> `MATDOG_16M_2x5M_NVS_V1` (`partitions.csv`, `PartitionScheme=custom`), and `scripts/upload.sh`
> refuses every full-image upload. **Do not use this tree to update the robot.**
> - The version literal remains `0.2.0-dev.3`. On 2026-10-10 the installed image moved to the
>   hardware-validated **LED-only** build `fee9383` (RMT DMA + dirty-frame); this source tree
>   includes its two exact LED blobs. A build of `main` is **not** that installed image.
> - The historical dev.3 Hardware Validation of 2026-10-07 remains acceptance BLOCKED. The
>   2026-10-10 LED-specific hardware check passed, but it does not approve a general firmware
>   release, another flash, or any motion.
> - The pure motion library under `src/motion` is unwired. Its execution suites and the
>   G35/G4/G4.1/G5-A evidence are deferred.
>
> `MOTION_AUTHORIZED=0`, `RESTORE=NOT_IMPLEMENTED`. See
> [`FLASH_LAYOUT_SAFETY_NOTICE.md`](FLASH_LAYOUT_SAFETY_NOTICE.md).

```text
MATDOG Controller
├── core/system      boot, version, health aggregation, power-state machine,
│                    cooperative non-blocking scheduling, USB command router
│                    ActuatorAuthority — the one arbiter of actuator write authority
├── calibration/     CalibrationDomain — pure model recovered from the LF V25 oracle
│                    CalibrationManager — session lifecycle over ActuatorAuthority
├── config/          HardwareProfile — the single USB_ONLY / ROBOT_POWERED authority
├── servo/           ServoBus — ST3215 / Seeed bus transport, read-only diagnostics
│                    ServoPopulation / ServoCensus — canonical 17 vs expected-now 13,
│                    live census classification (pure, transport-independent)
├── imu/             Bno085Imu — SH2_ROTATION_VECTOR acquisition, viewer-compatible
├── power/           DalyBms — read-only Modbus RTU battery telemetry
├── network/         WifiPolicy — pure Wi-Fi lifecycle state machine (host-linkable)
│                    WifiManager — the only translation unit that owns the radio
├── update/          OtaPolicy / OtaBootGuard / Sha256 — pure OTA state machine,
│                    first-boot rollback lifecycle, image identity (host-linkable)
│                    OtaEspBackend — the only unit that calls esp_ota_*
│                    OtaManager — Controller-facing owner; no transport in OTA-A
└── status/          LedRing — WS2812B ring, boots OFF, non-blocking effects
```

## Current hardware status — 2026-10-01

> **Historical snapshot (2026-10-01), not the current hardware state.** The results below are
> kept unchanged as evidence of that date. The robot has since been migrated to layout
> `MATDOG_16M_2x5M_NVS_V1` and runs the dev.3 candidate. See
> [`FLASH_LAYOUT_SAFETY_NOTICE.md`](FLASH_LAYOUT_SAFETY_NOTICE.md) for the current flash
> situation.

**TRUE Full Calibration: HARDWARE-VALIDATED 24/24.** The LF V25-derived full-leg sequence was
run on the real robot: LF/RF/RH/LH each reached `HARDWARE_CONTACT_CALIBRATED` 6/6 on the first
attempt. Firmware `dfcecb670d0565d2db1a8152b6cd7ad230bdb87d` (`ROBOT_POWERED`) ended SAFE_OFF 13/13 verified.

The 12 fresh q0 values and 24 contacts were exported and archived ([hardware-validation report](../../09_Logs/Validation_Reports/Full_Calibration_24_Contact_Hardware_2026-10-01/README.md)).
Calibration is RAM-only; the export is not an implemented boot restore. No operational envelope
is approved, and stand/gait hardware motion remains blocked. The frozen Controller V0.1 release
is distinct from the later development firmware validated in this session.

The [2026-09-29 calibration overview](#calibration-on-main-2026-09-29) below is retained as a
historical software-only snapshot, not the current project status.

## Official baseline

| Identity | Value |
|---|---|
| Official release tag | `matdog-controller-v0.1.0` |
| Tagged repository commit | `c54862f38a9cbd5e46d6b1770a6d109cc99b5c02` |
| Exact validated firmware source | `5b371da5482f9b0bd2df1c37ed361250ea54ae8f` |
| Validated application SHA256 | `6e6d92f898dbe95000b53dbb252c7eb5d3deaa9a4b161e2b1934436a76b29364` |
| Validated profile | `USB_ONLY` |

The tag identifies the official repository baseline; the source commit identifies the exact code
compiled, flashed and exercised. They are intentionally different because validation documentation
was committed after the firmware source. See [`VALIDATION.md`](VALIDATION.md) for the evidence and
scope.

## Permanent runtime direction

`MATDOG_Controller` is the permanent firmware architecture. Future reviewed stages are expected to
integrate Diagnostics, Maintenance, Service, Servo QC, Provisioning, Full Leg Calibration,
Wi-Fi/OTA and host transport here, followed later by Motion, IK, Gait and Stabilization.

The preserved Full Leg Calibrator V1 tree — annotated tag
`archive/2026-08-29/full-leg-calibrator-v1-h0` -> `15f3fb8f378e6cadf6bc479bfcaca2947741c9fd`, from
the former branch `matdog/full-leg-calibrator-v1`, archived 2026-09-18 — is an oracle for
calibration-engine, safety and evidence logic, not a replacement runtime and not a tree to merge
wholesale. Likewise, the
frozen [`ST3215_Bench_Tools`](../ST3215_Bench_Tools/README.md) remain immutable evidence even when
equivalent service capabilities are later integrated here.

## Standalone sources remain the evidence trail

Nothing under `05_Firmware/ST3215_Bench_Tools/` or `~/MATDOG/runtime/esp32/` was
modified. This firmware **adapts** hardware-proven transport/protocol code from those
sources into modules; it does not replace them as diagnostic tools. Full provenance,
SHA256 hashes and exactly what was preserved vs. deliberately left out is in
[`SOURCE_PROVENANCE.md`](SOURCE_PROVENANCE.md).

## Build

```bash
scripts/build.sh
```

Wraps `arduino-cli compile` with the pinned FQBN and injects a build id (short git SHA,
`-dirty` suffix if the tree has uncommitted changes) visible in the boot banner and
`@STATUS`:

`PartitionScheme=custom` makes the build take its partition table from `partitions.csv`
(`LAYOUT_ID=MATDOG_16M_2x5M_NVS_V1`, pinned by `scripts/matdog_layout.py`; the legacy
`app3M_fat9M_16MB` scheme is refused):

```text
esp32:esp32:esp32s3:USBMode=hwcdc,CDCOnBoot=cdc,UploadMode=default,CPUFreq=240,FlashMode=qio,FlashSize=16M,PartitionScheme=custom,DebugLevel=none,PSRAM=opi
```

Board: YD-ESP32-S3 N16R8 (16 MB flash, 8 MB OPI PSRAM, 240 MHz).

Every successful build also writes a **build manifest** next to the application
binary, inside the gitignored build directory:

```text
build/esp32.esp32.esp32s3/matdog_build_manifest.txt
```

It records the full source commit, build id, clean/dirty source state, selected
hardware profile, pinned FQBN, and the application binary's filename, size and SHA256.
`flash_app_only.sh` refuses to write anything it cannot verify against this file — see
Application-only flashing below. The manifest is a build artifact and is never
committed.

## Update and recovery policy

- **DECIDED — future normal update path:** Wi-Fi / OTA. It is not implemented in V0.1 *(V0.1
  statement; Wi-Fi/OTA V3 is on `main` since PR-2, OTA ingest disabled by default, hardware
  acceptance BLOCKED)*.
- **DECIDED — permanent wired service/recovery:** native USB CDC / USB-C remains available even
  after OTA is implemented. OTA must never remove the wired recovery path.
- **VALIDATED for the V0.1 baseline:** the application-only flashing workflow below operates over
  the wired USB service connection.

The phrase "OTA application partition" below names the ESP-IDF partition type. Writing that
partition with the current USB script is not an implementation of Wi-Fi/OTA.

## Application-only flashing

```bash
scripts/flash_app_only.sh
```

Writes **only** the currently-active OTA application partition — never the
bootloader, partition table or boot_app0/otadata. `scripts/verify_application_partition.py`
determines that partition's real offset/size by reading the device's own partition
table and otadata (layout `MATDOG_16M_2x5M_NVS_V1` has two 5 MiB OTA slots; a device that
still has the legacy table is refused, and the write range may never touch `matdog_nvs`;
this never assumes
which one is active, and recognizes OTA slots by the real ESP-IDF bitmask
`(subtype & 0xF0) == PART_SUBTYPE_OTA_FLAG`, not a numeric threshold that would also
match TEST/TEE partitions, and must be a contiguous set `{0, ..., N-1}` — a sparse OTA
layout like `{0, 2}` refuses rather than resolving). It also reads the real build's
`sdkconfig` as a three-way `SdkconfigFlag` (`ENABLED`/`DISABLED`/`UNKNOWN`) and refuses if
`CONFIG_BOOTLOADER_APP_ANTI_ROLLBACK` is `ENABLED` or `UNKNOWN`, or if
`CONFIG_BOOTLOADER_APP_ROLLBACK_ENABLE` is `UNKNOWN`, or if it is `ENABLED` *and* the
selected otadata entry is in a state (`NEW`/`PENDING_VERIFY`) the bootloader can
autonomously rewrite on the next boot — a symbol absent from the sdkconfig text entirely
is `UNKNOWN`, never silently treated as `DISABLED`. See `scripts/ota_partition_logic.py`
and `VALIDATION.md` Session 2.3. Refuses to run unless: the working tree is clean and the
compiled binary's embedded build id matches `HEAD`, the 16 MiB full-flash backup
verifies, the static audit passes, and the connected device's MAC matches the expected
one. Prints `SDKCONFIG_ROLLBACK`/`SDKCONFIG_ANTI_ROLLBACK`/`DEVICE`/`APPLICATION_BINARY`/
`APPLICATION_SHA256`/`APPLICATION_OFFSET`/`APPLICATION_SIZE`/`MAX_PARTITION_SIZE`/`FQBN`/
`SOURCE_COMMIT` before writing anything, and independently re-verifies the write
afterward with `esptool verify-flash`.

### Hardware-profile provenance gate

`build.sh` can produce a `USB_ONLY` **or** a `ROBOT_POWERED` image from the same commit,
at the same path. The commit/build-id gate above cannot tell them apart — the build id
is identical for both — so a stale image of the wrong profile could be written under the
wrong assumption. Every flash is therefore additionally gated on the build manifest and
on the operator naming the profile they intend:

```bash
scripts/flash_app_only.sh                                 # defaults to USB_ONLY
MATDOG_FLASH_PROFILE=ROBOT_POWERED scripts/flash_app_only.sh
```

Fail-closed. The write proceeds only if **all** of these hold: the manifest exists and
parses; its schema version is known; its source commit equals `HEAD`; the tree was clean
at build time *and* is clean now; the binary exists and its size **and** SHA256 equal the
recorded ones; the manifest profile is recognized; and it equals the requested profile.

| Manifest | Requested | Result |
|---|---|---|
| `USB_ONLY` | `USB_ONLY` (default) | allowed, subject to all other gates |
| `ROBOT_POWERED` | `ROBOT_POWERED` (explicit) | allowed, subject to all other gates |
| `ROBOT_POWERED` | default / unspecified | **REFUSE** |
| `USB_ONLY` | `ROBOT_POWERED` | **REFUSE** |
| unknown / missing profile | any | **REFUSE** |
| size or digest mismatch | any | **REFUSE** |
| commit mismatch, dirty tree, missing/unparseable manifest | any | **REFUSE** |

The verified profile is printed in a banner immediately before the write, so the operator
sees what is actually going on the device. Logic and refusal reasons live in
`scripts/build_manifest.py`, with offline tests in `scripts/tests/test_build_manifest.py`.

`scripts/upload.sh` is a refusing stub since P2.3: it performs no hardware operation and exits
1. It used to run a full Arduino upload (bootloader + partition table + boot_app0 +
application, every time), which on layout V1 can put the old partition table back or
move/erase `matdog_nvs`. A migration from the legacy layout is a separate, explicitly
authorized procedure. See `VALIDATION.md` Session 2 for why the earlier "application-only"
framing of the full upload was wrong.

## Static safety audit

```bash
python3 scripts/static_audit.py
```

Regression tripwire (not a formal verifier) that fails the build if forbidden
functionality leaks in: `CalibrationOfs`, EEPROM ID/offset writes, automatic
torque-on, `GoalPosition`/motion primitives, automatic BNO085 DCD save, any DALY
write, duplicate GPIO ownership, a UART peripheral collision between ServoBus and
DalyBms, a synchronous multi-ID servo scan loop, `@SERVO SCAN`/`@SERVO READ` losing
their `MAINTENANCE`-mode guard (or `@SERVO SAFE_OFF` gaining one), the LED transport
being driven while `kLedRailPowered` is false, `scripts/flash_app_only.sh` regressing
to reference the bootloader/partition-table/boot_app0 artifacts it must never write,
the OTA partition verifier's fail-closed validity checks regressing (it also runs
that verifier's own offline test suite as part of the audit), the OTA subtype filter
regressing to a numeric threshold instead of the real bitmask, an OTA slot set losing
its contiguous-starting-at-0 requirement, the sdkconfig parser losing its `UNKNOWN`
case (silently treating an absent symbol as `DISABLED` again), the rollback/anti-rollback
parameters gaining an unsafe default, `ServoBus::begin()` assigning `IOTimeOut` directly
again instead of via `ScopedIOTimeout`, `safeOff()`/`readRuntimeState()` using the
diagnostic timeout instead of the operational one, or `safeOff()` classifying success
from `EnableTorque()`'s own return value instead of an independent readback.

G2 additions: the three rail flags regressing from derived values back to independently
editable literals, `expectationsFor()` mismapping a profile, **the compiled-in default
profile being anything other than `USB_ONLY`** (the G3 authorization gate — a
`ROBOT_POWERED` image must never be producible by an unreviewed edit), the servo
population model losing the canonical-17 / expected-now-13 / absent-by-design-4
distinction or drifting from `MATDOG_SERVO_ALLOCATION.yaml`, a "17 responders = PASS"
threshold reappearing, `ServoPopulation`/`ServoCensus` gaining a `Serial` or `<Arduino.h>`
dependency, `Controller::begin()` starting a scan/census at boot, and a direct
network-handler → servo-primitive path. It also compiles and runs the offline C++ census
suite (`scripts/tests/run_host_tests.sh`) as part of the audit, the same way it already
runs the OTA parser's Python suite.

DALY KEY probe additions (2026-09-19): the DALY firmware may transmit **only** the two
whitelisted FC03 read frames (`D2 03 00 00 00 3E D7 B9`, `81 03 01 00 00 78 5B D4`), each
re-verified byte-for-byte with function `0x03` and CRC-16/MODBUS, through exactly one
`bms_uart_.write(dalyRequestFrame(request), kDalyRequestLen)`; any other initialized byte array,
`bms_uart_` use, UART2 route, FC06/FC10 literal or write helper fails. `requestDischargeOff()`
stays a no-op; `@BMS` commands take no arguments and name no write; `@BMS KEY READ` keeps its
`MAINTENANCE` gate and `@BMS KEY STATUS` never starts a transaction; the KEY probe may not leak
into power-state/health logic; `DalyProtocol.*` stays Arduino-free. The audit also runs
`scripts/tests/test_static_audit_daly.py`, which proves those rules fail on mutation (e.g. the KEY
request function `0x03 → 0x06`). The G3.1 TX-ring floor rises from 2560 to 3072 bytes because the
largest single loop pass grew (now 2674 bytes; see `VALIDATION.md`).

DALY KEY discharge configuration additions: the one permitted write is spelled out in
`DALY_THE_ONE_WRITE` (FC06, `0x81`, `0x0120 := 0x005A`). The parameterless
`dalyKeyLogicDischargeWriteFrame()` must match the reviewed recipe exactly; the selector must map
each request to its own frame; the write can be requested only through `@BMS KEY SET DISCHARGE
CONFIRM` (MAINTENANCE-gated, live operating mode) → `DalyBms::requestKeyLogicDischarge(mode)` →
the scheduler, once each. FC10, any other register (MOS control `0x0121`/`0x0122` included), value,
address or second write frame, a caller-supplied target, a generic `@BMS` write spelling, DALY
persistence and any `requestDischargeOff()` body fail the build; the mutation suite proves it.

## USB diagnostic command surface

```text
@HELP
@STATUS
@IMU STATUS | @IMU STREAM ON|OFF
@BMS STATUS | @BMS STREAM ON|OFF
@BMS KEY READ                               (MAINTENANCE mode only; read-only)
@BMS KEY STATUS                             (cached; no bus transaction)
@BMS KEY SET DISCHARGE CONFIRM              (MAINTENANCE only; the ONE DALY write; once per boot)
@BMS KEY WRITE STATUS                       (cached; no bus transaction)
@LED STATUS | @LED OFF | @LED TEST
@WIFI STATUS                                (cached snapshot; never queries the radio)
@WIFI ON | @WIFI OFF                        (any mode; refused without credentials)
@OTA STATUS                                 (read-only; OTA-A ships no transport)
@AUTHORITY STATUS                           (read-only)
@ACTUATOR STATUS                            (read-only)
@CALIBRATION STATUS                         (read-only)
@CALIBRATION Q0 CAPTURE 9 16 CONFIRM_Q0_POSE          (MAINTENANCE + ROBOT_POWERED; read-only, Torque OFF)
@CALIBRATION Q0 STATUS | Q0 ABORT
@CALIBRATION Q0 PROMOTE CONFIRM_CURRENT_INSTALLATION  (MAINTENANCE; RAM only; promotes THAT capture)
@CALIBRATION SESSION START <LF|RF|RH|LH> CONFIRM_CURRENT_Q0
@CALIBRATION MOTION PERMIT GRANT 16 CONFIRM_FIRST_MOTION | MOTION PERMIT REVOKE | MOTION ABORT
@CALIBRATION FULL LEG <LF|RF|RH|LH> CONFIRM_FULL_CALIBRATION | FULL LEG STATUS | FULL LEG ABORT
@CALIBRATION EVIDENCE EXPORT                (read-only, deterministic)
@CALIBRATION SESSION ABORT
@SERVO SCAN <lo> <hi> | @SERVO READ <id>   (MAINTENANCE mode only)
@SERVO CENSUS                               (MAINTENANCE mode only)
@SERVO SAFE_OFF <id>                        (always allowed, any mode)
@MODE STATUS | @MODE MAINTENANCE | @MODE RUN
@SYSTEM SHUTDOWN
```

USB CDC transmit can never stall the Controller loop (G3.1): `Controller::begin()` sets the
HWCDC TX timeout to 0 and the TX ring to 3 KB before `Serial.begin()`, so output nobody
drains is dropped instead of waited for. Command replies are expected complete while a host
is reading and draining; right after reopening a port that was closed for a long time, a
stale backlog can still occupy the ring and a reply may short-write rather than block. That
best-effort delivery belongs to this diagnostic surface only; a future HostLink defines its own framing, acknowledgement and reliability.

`@SERVO SAFE_OFF` can only disable torque, never enable it, and stays reachable in
every operating mode — it is the safety de-escalation path. Its reply is never a bare
`OK`: `SCS::Ack()` (which `EnableTorque()` returns) gives `0` on any failure/timeout,
not `-1` like `Ping()`/`readByte()` — a naive `result >= 0` check is therefore always
true and can never observe a failure. `safeOff()` now always performs an independent,
read-only `TorqueEnable` readback after the write and classifies strictly from that:
`VERIFIED_OFF` (readback confirms `0`), `UNVERIFIED_NO_RESPONSE` (no readback response
at all — confirmed live with the servo bus unpowered), or `VERIFY_FAILED` (readback
responded but is non-zero). `@SERVO SCAN`/`@SERVO READ`
are **incremental with bounded per-ID blocking, not non-blocking**: `ServoBus::update()`
still calls `SCServo::Ping()` synchronously, which carries its own bounded per-call
timeout (`kDiagnosticTimeoutMs`, 20ms — see Operating mode below). `@SERVO SCAN` replies
`SERVO_SCAN=STARTED` immediately and the router reports `SERVO_SCAN=COMPLETE
elapsed_ms=.. max_ping_us=..` asynchronously once the scan's one-`Ping()`-per-tick state
machine finishes; that duration is measured, not assumed. Because a scan/read call can
still block for a bounded-but-real amount of time, both commands refuse outside
`MAINTENANCE` mode (`SERVO_SCAN=BLOCKED` / `REASON=NOT_IN_MAINTENANCE_MODE`) — see
Operating mode below. `@LED TEST`/`@LED OFF` are refused/no-op under the current
`USB_ONLY` profile — see Anti-back-power below. `@SYSTEM SHUTDOWN` walks the
power-state machine through its shutdown sequence but always resolves to
`POWER_CUT_FAILED` in V0.1, because the DALY K-Series `Discharge MOS OFF` write
protocol has not been identified or bench-verified (see `VALIDATION.md` and handoff
section 8A.8). No command in this surface can write servo EEPROM, recode an ID, save
the BNO085 DCD, or write DALY MOS state; the only DALY configuration write is the single
semantic KEY setting below.

`@BMS KEY READ` is the read-only DALY KEY probe (implemented and **live-verified read-only**
2026-09-19; see `VALIDATION.md`). It queues one FC03 read of the DALY's second Modbus personality —
`81 03 01 00 00 78 5B D4`, byte-identical to the parameter-block read in DALY's official BMSTool
V1.14.79 — replies `BMS_KEY_READ=STARTED` (or `BUSY` while one is outstanding, `BLOCKED` outside
`MAINTENANCE`), and reports asynchronously — the block below is the **pre-commissioning** live
example captured on 2026-09-19, *before* the single configuration write:

```text
BMS_KEY_READ=COMPLETE result=OK
  key_logic_raw=0x0055 key_logic=DISABLED
  charge_mos_control=1
  discharge_mos_control=1
  sleep_time_raw=360 sleep_time_s=3600
```

or `BMS_KEY_READ=COMPLETE result=TIMEOUT|CRC_FAIL|BAD_HEADER rx_bytes=<n>`. The reply must be
exactly 245 bytes, `51 03 F0`, CRC-valid.

After the single verified commissioning write, the **current last verified value is `0x005A`
DISCHARGE**, so a new read on this unit should normally report `0x005A` unless the BMS was reset,
replaced or reconfigured.

Decoded registers (BMSTool static analysis, read side live-verified on MATDOG's unit): `0x0120`
KEY logic (`0x55` DISABLED, `0xA5` DISCHARGE_AND_SLEEP, `0x5A`
DISCHARGE, `0xAA` CHARGE_AND_DISCHARGE, `0xA6` CHARGE_DISCHARGE_AND_SLEEP, anything else
UNKNOWN), `0x0121`/`0x0122` charge/discharge MOS control, `0x0115` sleep time (raw × 10 s as
BMSTool displays it). One transaction owner (`DalyBusScheduler`) starts both this read and
telemetry, so they never overlap; the KEY read goes first at the next idle boundary, defers at
most one 2 s telemetry poll, and telemetry resumes on its own. A failed read never replaces the
last valid snapshot and never marks the BMS absent. `@BMS KEY STATUS` prints the cached
result/snapshot and its age with zero bus traffic (`snapshot=NOT_READ key_logic=UNKNOWN` until a
read succeeds). Nothing is inferred from the live MOS state.

**Why the commissioning write is retained** (reviewed 2026-09-20). With the register now reading
`0x005A`, the gate answers `ALREADY_CONFIGURED` and transmits nothing, so the command is inert on
this BMS: it can only act again on a unit that reads exactly `0x0055` — a replaced or
factory-reset BMS, which is precisely the re-commissioning case. Removing it would delete the only
Linux-side recovery path (DALY's own BMSTool is Windows-only) while removing no capability that is
currently reachable, so it stays as tightly gated maintenance functionality. It must never be
broadened: no second register, value, argument or alias.

`@BMS KEY SET DISCHARGE CONFIRM` is the **only** DALY write (implemented and sent live **once**,
2026-09-19: acknowledged and read back as `0x005A` — see `VALIDATION.md`). It
sends FC06 `81 06 01 20 00 5A 16 07`: KEY logic `0x0120 := 0x005A` (DISCHARGE — KEY OFF turns the
discharge MOS off, charge MOS kept), the exact frame DALY BMSTool V1.14.79 builds for that setting.
It takes no argument and refuses with zero bytes sent (`BMS_KEY_WRITE=REFUSED reason=…`) unless:
MAINTENANCE; no write already sent this boot; no DALY transaction in flight or queued; `0xD2`
telemetry OK and ≤ 5 s old; no alarms; a successful `@BMS KEY READ` ≤ 30 s old showing exactly
`0x0055` with charge/discharge MOS control `1`/`1` (`0x005A` → `ALREADY_CONFIGURED`). Accepted, it
replies `BMS_KEY_WRITE=STARTED target=DISCHARGE raw=0x005A`, re-checks every precondition (the
live operating mode included) just before
transmitting, then reports `BMS_KEY_WRITE=ACK result=OK|TIMEOUT|CRC_FAIL|BAD_HEADER|BAD_ECHO
rx_bytes=<n>` (only the exact echo `51 06 01 20 00 5A 05 97` is `OK`) and, after an automatic
FC03 read-back, `BMS_KEY_WRITE=COMPLETE ack=… readback=VERIFIED|PENDING_RESTART|MISMATCH|READ_FAILED`
with the decoded register. Only `VERIFIED` (`0x005A` read back) means the setting is stored;
`PENDING_RESTART` means the BMS still reports `0x0055` (BMSTool asks for a BMS restart after every
setting — MATDOG never restarts the BMS). `@BMS KEY WRITE STATUS` prints the cached record with
zero bus traffic. Nothing persists on the ESP32: if it loses power after the write, `@BMS KEY
READ` after reboot shows the real register. No rollback command exists.

`@STATUS` (and the per-module `@IMU`/`@BMS`/`@LED` variants) report each module as
`init=.. detected=.. expected=.. result=..` — separating "did the driver initialize"
from "was the hardware actually detected" from "was it expected to be reachable right
now" from "is that a problem". See `src/core/Availability.h`; under `USB_ONLY`:

```text
BNO085 init=OK       detected=ONLINE      expected=REQUIRED  result=PASS
DALY   init=OK       detected=NO_RESPONSE expected=OFFLINE   result=PASS
SERVO  init=OK       detected=UNKNOWN     expected=OFFLINE   result=PASS
LED    init=DEFERRED detected=UNPOWERED   expected=UNPOWERED result=PASS
SERVO_POP canonical=17 expected_now=13 absent_by_design=4 last_census=NOT_RUN
```

`last_census=NOT_RUN` is the honest answer after a boot with no census: no servo bus
transaction ever happens automatically, so `@STATUS` must never imply a population was
verified.

### "Not observed" is not a verdict

`detected=UNKNOWN` means *nothing has established anything* — it is the absence of
evidence, not evidence of absence. `detected=NO_RESPONSE` means *we asked and it did not
answer*. `classify()` keeps these distinct:

```text
UNKNOWN     + REQUIRED            -> UNKNOWN   (not proven; system reports BOOTING)
UNKNOWN     + OPTIONAL            -> PASS      (absence would not even be a fault)
UNKNOWN     + OFFLINE/UNPOWERED   -> PASS
NO_RESPONSE + REQUIRED            -> FAULT     (a real observed failure)
NO_RESPONSE + OPTIONAL            -> DEGRADED
NO_RESPONSE + OFFLINE/UNPOWERED   -> PASS
```

This matters for two modules under `ROBOT_POWERED`. A WS2812 chain has no readback path
at all, so the LED ring's `detected` is permanently `UNKNOWN` when powered; treating that
as `DEGRADED` made `SystemHealth::READY` unreachable on a perfectly healthy robot.
Separately, nothing probes the servo bus at boot (no automatic scan is allowed), so
`REQUIRED + UNKNOWN` reported `FAULT` before anyone had asked the bus a single question.

Neither is fixed by faking a physical observation: the LED still reports
`detected=UNKNOWN` in `@STATUS`, and `detectedStateForLedRail()` is forbidden by the
static audit from ever returning `ONLINE`. An *observed* failure still escalates exactly
as before. Under `ROBOT_POWERED` the system therefore reads `BOOTING` until the servo bus
is actually probed, `READY` once it answers, and `FAULT` if it is probed and does not.

## Hardware profile (USB_ONLY / ROBOT_POWERED)

`src/config/HardwareProfile.h` is the **single authority** for which physical power
configuration the firmware is built for. V0.1 stated the bench configuration four times
over — a `kTestProfile` string plus three independent `constexpr bool` rail literals —
with nothing tying them together, so a partial edit could produce a firmware whose
printed profile name contradicted its own expectations. Now there is one enum, one
mapping table, and everything else is derived:

```text
USB_ONLY       servo_power=NO  battery=NO  led_rail=NO
ROBOT_POWERED  servo_power=YES battery=YES led_rail=YES
```

`BuildConfig.h` selects exactly one profile and derives `kServoPowerAvailable`,
`kBatteryAvailable`, `kLedRailPowered` and `kTestProfile` from it. Each module's
`ExpectedState` then comes from one shared derivation in `core/Availability.h`
(`expectedStateForServoBus`/`Battery`/`LedRail`) instead of an inlined ternary repeated
per module. The V0.1 `Availability` model itself is unchanged: the same `classify()`
turns an unchanged `NO_RESPONSE` into `PASS` under `USB_ONLY` and `FAULT` under
`ROBOT_POWERED`, which is exactly what it was designed for. The LED ring is deliberately
`OPTIONAL` even when powered — a dead status ring must never fault an otherwise healthy
robot.

Switching profiles is a **one-symbol change**:

```bash
MATDOG_PROFILE=ROBOT_POWERED scripts/build.sh    # one build, source default untouched
```

The source default (`MATDOG_ACTIVE_HARDWARE_PROFILE` in `BuildConfig.h`) is `USB_ONLY`
and `static_audit.py` fails the build if it is anything else, because powered hardware
validation (G3) is a separately authorized gate. The override is deliberately loud:
`build.sh` prints the selected profile and the boot banner reports it with its rail
facts, so a `ROBOT_POWERED` image cannot be produced or flashed silently.

A profile describes the **power/rail** configuration only. Which servos are physically
installed is an orthogonal fact, owned separately — see below.

## Servo population and census

`src/servo/ServoPopulation.h` keeps three populations explicitly distinct:

```text
CANONICAL_ALLOCATED               17   every bus ID the MATDOG design allocates
EXPECTED_IN_CURRENT_CONFIGURATION 13   physically installed today
ABSENT_BY_DESIGN                   4   52 NECK_PITCH, 53 HEAD_ROTATION,
                                       54 HEAD_PITCH, 55 JAW — allocated and
                                       bench-provisioned, not yet mounted
```

A healthy powered census for the current robot is therefore **13 present + 4 absent by
design**, not 17. "17 must respond for PASS" is false for this robot and the static
audit fails the build if such a threshold reappears.

`@SERVO CENSUS` scans the canonical range 11–55 and classifies every ID:

```text
PRESENT_EXPECTED          installed-now servo answered              healthy
ABSENT_BY_DESIGN          not-installed servo stayed silent         healthy
MISSING_EXPECTED          installed-now servo did NOT answer        problem
ABSENT_BY_DESIGN_PRESENT  not-installed servo ANSWERED              problem, surfaced
UNEXPECTED_ID             responder outside the canonical table     problem
NOT_PROBED                canonical ID outside the scanned range    inconclusive
```

Verdict is `PASS`, `PROFILE_MISMATCH`, `RANGE_INCOMPLETE` or `NOT_RUN`. It is
fail-closed: a scan that did not cover every canonical ID, or whose responder list
overflowed, can never report `PASS` — silence only means something where a probe
actually happened.

The embedded canonical table is a deliberately minimal projection of
`06_Software/Matdog_Core/config/MATDOG_SERVO_ALLOCATION.yaml`, which remains the
canonical **project** authority (unit identity, provisioning sessions, cold-verify
evidence). The static audit cross-checks the two so drift cannot pass silently; if they
ever disagree, the YAML wins.

**Architecture note.** `ServoBus` answers "what did the physical bus observe";
`ServoPopulation` answers "what does that mean for this robot"; `ServoCensus` is the
Controller-owned service that runs one and holds the structured result; `CommandRouter`
only *formats* it. Nothing in the population/census layer includes `<Arduino.h>` or
touches `Serial`, so the offline host tests link the shipped logic rather than a copy,
and a future Web UI / HostLink adapter can render the same `CensusResult` without
re-scanning the bus or reimplementing the classification.

The census is strictly read-only (`Ping()` only) and is **never started automatically** —
not at boot, not on a timer.

## Offline tests

```bash
python3 scripts/tests/test_ota_partition_logic.py   # OTA slot selection (40 tests)
bash scripts/tests/run_host_tests.sh                # servo population / profile + DALY protocol
                                                    # + Wi-Fi + OTA-A + ActuatorAuthority
                                                    # + safe actuator write policy
                                                    # + calibration bootstrap geometry
                                                    # + calibration domain & manager
python3 scripts/tests/test_static_audit_daly.py     # DALY write-whitelist mutation suite
python3 scripts/tests/test_static_audit_safe_actuator.py  # safe actuator boundary mutation suite
python3 scripts/static_audit.py                     # runs all of the above, plus the audit
```

`scripts/tests/test_servo_population.cpp` compiles the **real** firmware translation
units (`ServoPopulation.cpp`, `Availability.cpp`) on the host with `g++ -Wall -Wextra
-Werror` — no Arduino runtime, no device, no test framework. It covers the canonical/
expected-now distinction, every per-ID classification, missing/unexpected/
absent-but-present cases, the fail-closed partial-scan and truncation paths, and both
profiles' expected-hardware semantics (proving `USB_ONLY` behaviour did not regress
while `ROBOT_POWERED` was added).

`scripts/tests/test_daly_protocol.cpp` does the same for `src/power/DalyProtocol.cpp`: both
request frames and their CRCs, the 245-byte `0x81` reply built from BMSTool's literal byte
positions (proving the register-based offsets), all KEY-logic values, sleep-time width, rejection
of bad header/CRC/length without replacing the last valid snapshot, the unchanged `0xD2`
telemetry decoder, and the bus scheduler (no overlap, KEY priority, bounded telemetry deferral,
automatic resumption). It also covers the one write: its exact bytes and CRC, the acknowledgement
exactly as BMSTool accepts it (address, function, CRC, register and value echo, length), every
precondition and its order, `ALREADY_CONFIGURED`, read-back classification (an ACK alone is never
verification), the status tracker, and scheduling of write → read-back → telemetry after success,
failure and timeout.

`scripts/tests/test_wifi_policy.cpp` does the same for `src/network/WifiPolicy.cpp`: the
credential gate (no SSID configured means the radio is never started, under any number of
ticks), the two-phase radio start, the one-transition-per-tick rule, the connect deadline,
the doubling backoff ladder and its 60 s ceiling, reset-on-success, link loss restarting the
ladder from the bottom, operator enable/disable (including that no teardown is issued for a
radio that was never brought up), fail-closed handling of a refused radio start or connect
call, the invariant that a connect is never issued while connected, `millis()` wraparound,
and the IPv4 formatter including its bounds.

`scripts/tests/test_ota_policy.cpp` does the same for `src/update/OtaPolicy.cpp`,
`OtaBootGuard.cpp` and `Sha256.cpp`, with a fake `OtaBackend` substituting only the flash.
468 checks: target resolution refusals (target == running, factory/TEST subtype, no inactive
slot, oversize, zero length, and exactly-partition-sized which must be *allowed*), metadata
refusals, the PENDING_VERIFY precondition, every stream failure (open rejected, write error,
short write, truncation, overrun, `esp_ota_end` failure, hash mismatch against a different
image of the same length), the ordering property that the boot target does not move from any
state other than `IDENTITY_VERIFIED`, replay/idempotence, and the whole first-boot rollback
lifecycle. SHA-256 is checked against the FIPS 180-4 vectors and against itself at eight
chunk sizes.

`scripts/tests/test_actuator_authority.cpp` does the same for
`src/core/ActuatorAuthority.cpp`. 751 checks, with the conflict matrix exhaustive rather than
illustrative: all 20 ordered pairs of distinct write-capable owners, each challenger tried in
**its own** legal operating mode so a rejection can only be about exclusivity. Also: boot and
re-init always landing on `NONE`, corrupted enum values failing closed, release refused for every
non-owner, the stale-lease case the generation exists for, force-clear under every reason, the
mode-compatibility table, a mode change clearing a stranded owner, and the whole inhibit
lifecycle.

`scripts/tests/test_calibration_domain.cpp` and `test_calibration_manager.cpp` cover
`src/calibration/`: 702 domain checks including the 24-profile completeness derived from the
Cartesian model, the three meanings of 2048 pinned apart, the physical-unit identity trap
(unit M11 versus M33 in the LF lower slot), the leg population gate, the evidence lifecycle with
every shortcut refused, and the LF V25 oracle replay; plus 322 manager checks against the **real**
`ActuatorAuthority`, including the end-to-end stale-lease scenario where a finished session's late
events are fired at a live one and must not touch it.

## Calibration on `main` (2026-09-29)

> **HISTORICAL / SUPERSEDED status snapshot.** Current 24/24 hardware result is above.

**Status: IMPLEMENTED / OFFLINE TESTED. The four-leg Full Calibration has NOT been run on
hardware.** The sections *Calibration foundation* and *Safe Actuator Layer* below are the
historical record of how the foundation was built; where they say "no write path" or "runtime
adapter TO_IMPLEMENT", those statements are historical, not current status.

- **Write path.** A bounded production `ServoBusActuatorBackend` exists and is reachable only
  through the Safe Actuator layer: `ActuatorAuthority` lease, a live calibration session, a fresh
  RAM motion permit and Geometry V5 targets. Nothing writes servo EEPROM, `PositionOffset`, an
  ID or NVS in this path; every calibration record is RAM.
- **q0.** `@CALIBRATION Q0 CAPTURE` produces twelve `CANDIDATE` q0 records read-only (Torque
  OFF, nine samples per joint). `@CALIBRATION Q0 PROMOTE` promotes **that same capture** —
  `prepareFreshQ0Evidence` over the capture session's `FreshQ0Capture` view — through the one
  shared CR3 accept-and-promote rule, all twelve or none, and **replaces** the previous q0 in
  `JointTransformTable`. The frozen CR2-C package (`prepareCurrentQ0Evidence`) is kept only as a
  regression oracle; production code and the static audit forbid using it. `SESSION START`
  refuses (`CURRENT_BOOT_Q0_NOT_PROMOTED`) unless the table holds exactly the current capture.
- **Full Leg Calibration.** Generalized to LF, RF, RH, LH: UPPER MIN contact, an optional
  auxiliary park, UPPER MAX contact, `SAFE_OFF`, then the evidence lifecycle. Parking: LF→
  `LH_UPPER` (bus 42), RF→`RH_UPPER` (bus 32), RH and LH none. Evidence export is deterministic.
- **Acceptance levels.** `HARDWARE_CONTACT_CALIBRATED` is the next hardware acceptance level.
  `FINAL_OPERATIONAL_ENVELOPE_ACCEPTED` is unavailable until an approved stand/gait workspace
  sets `kFullLegOperationalParametersApproved` (audit-pinned `false`); 0/12 final
  `JointLimits` are admitted on purpose.
- **Persistence.** Calibration Persistence V1 is on `main` since PR-1 (2026-10-08).
  - Storage: record and codec, A/B store in the dedicated `matdog_nvs` partition, persistent
    SAVE recovery marker, durable acknowledgment.
  - Commands: `@CALIBRATION PERSIST STATUS | SAVE CHECK | SAVE CONFIRM_SAVE_FULL_CALIBRATION |
    ACK | RECONCILE`.
  - Boot LOAD is information only: nothing is admitted into the transform table, and `RESTORE`
    is not implemented.
  - Offline/host-tested on `main`, with no hardware acceptance of a `main` build
    ([`ROADMAP.md`](../../01_Docs/02_Architecture/ROADMAP.md)).
- **Hardware procedure:** [`FULL_CALIBRATION_4LEG_HARDWARE_RUNBOOK.md`](FULL_CALIBRATION_4LEG_HARDWARE_RUNBOOK.md).

## Calibration foundation

**Status (historical, 2026-09-24): implemented, compiled, offline-tested. NOT hardware-tested. NO write path added.**

The installed robot's calibration is `CALIBRATION_RESET_PENDING_FULL_RECALIBRATION` and hardware
motion is **BLOCKED** — that is the repository's own declaration, and
`MATDOG_CALIBRATION_HARDWARE_MOTION_AUTHORIZED` defaults to `0` so a live session is refused
before the arbiter is even asked.

The LF V25 archive is a **historical hardware oracle**, replayed offline and matched. It is not
current calibration and cannot become it: every replayed record carries `HISTORICAL_REPLAY`, and
`mayPromote()` refuses that origin.

The full audit — source precedence, what LF V25 actually proved, the three evidence vocabularies,
four discrepancies including the two unrelated meanings of "H1", the Generic V25 component
assessment and the EEPROM boundary — is in
[`CALIBRATION_SOURCE_PRECEDENCE.md`](CALIBRATION_SOURCE_PRECEDENCE.md).

## Operating mode (MAINTENANCE / RUN)

`core::OperatingMode` (`src/core/OperatingMode.h`) is a deliberately tiny boundary —
an enum and a two-line manager class, not a state machine — between potentially
blocking servo diagnostics and a future deterministic motion loop:

```text
MAINTENANCE  servo scan/read diagnostics allowed; no motion allowed (none exists yet)
RUN          future motion loop; @SERVO SCAN/@SERVO READ refuse
```

V0.1 has no motion execution at all, so today this boundary gates diagnostics against
nothing but itself. The point is that it already exists, so a future motion-controller
integration cannot silently inherit `@SERVO SCAN`/`@SERVO READ` as callable from
inside a real-time `RUN` loop. Default is `MAINTENANCE` — there is no motion loop yet
to protect, and Session 2's already hardware-validated diagnostic workflow should not
regress for no protective benefit. **Whoever adds the motion controller must flip the
default to `RUN`** and require an explicit, reviewed transition into `MAINTENANCE`
(with torque confirmed off) before servo diagnostics are reachable again — this is
called out directly in `OperatingMode.h` so it cannot be missed.

The servo bus has two explicitly named timeouts, and every method states which one it
uses — there is no "default/untouched" case to trust implicitly (Session 2.3 Finding 1
corrected Session 2.2, where a single 20ms timeout was silently applied to every
transaction including `safeOff()`/`readRuntimeState()`, making the "100ms
operational / 20ms diagnostic" split not actually true in code):

```text
ServoBus::kDiagnosticTimeoutMs = 20   ping(), readModel(), the scan's per-ID probe —
                                       bounded absence-detection only, MAINTENANCE-only today
ServoBus::kOperationalTimeoutMs = 100 safeOff() (the safety de-escalation write, reachable
                                       from any OperatingMode) and readRuntimeState() (the
                                       primitive behind @SERVO READ today, which a future
                                       motion controller will naturally reuse)
```

`kDiagnosticTimeoutMs` is justified by real hardware measurement rather than an assumed
value: the NEW01 characterization campaign
(`09_Logs/Validation_Reports/ST3215_Provisioning_2026-08-27/characterization_sessions/`)
timed a live powered ST3215 at 1 Mbaud and recorded Ping+register-read round trips of
593-620us — 20ms is roughly 32x that measured worst case. `kOperationalTimeoutMs` is
simply SCServo's own untouched library default (100ms) — not a value MATDOG has
validated/optimized as final for the powered multi-servo bus (13 installed today, with 17
canonical allocation slots). Both are applied via
`ServoBus::ScopedIOTimeout`, a generic RAII guard around each individual bus transaction
that saves `SCSerial::IOTimeOut` (a public field, set at runtime — the vendored library is
never edited), applies the named timeout for that call site, and restores the previous
value on every exit path. `begin()` never assigns `IOTimeOut` directly, so neither timeout
can silently become a standing global override for some other call site.

## Wi-Fi / provisioning V3 — 2026-10-04

**IMPLEMENTED / OFFLINE TESTED; on `main` since PR-2; hardware acceptance BLOCKED.** No release
is approved.

> *Historical wording, 2026-10-04:* "This isolated branch is based on
> `1a5e0085098eeb907319f6f1a00693869444d9cf`, the latest local post-abort/persistence integration.
> Its calibration persistence hardware acceptance is not evidenced: **CAL_PERSIST_BASE is
> BLOCKED**. This branch is a provisional candidate, not a release." The branch no longer exists
> as a separate line; its content reached `main` through PR-2.

A core-0, low-priority worker owns radio and network NVS. `WifiManager::update()` copies
cached state with a zero-wait mutex; events only store a disconnect reason. One request
slot reserves `config_busy` before returning. Calibration mutations, persistence writes,
RUN entry and OTA preparation cannot overlap that reservation. Critical-state changes
cancel a trial, stop scans and keep modem sleep OFF. Network code cannot command servos.

Two infrastructure profiles share one STA; ACTIVE NVS takes precedence over the old
compile-time credentials. The radio stays ON with no credentials. Retry/backoff is
2–60 s; profiles alternate after failed attempts. Driver association scans all channels,
sorts by signal and never pins a BSSID. Optional roaming defaults OFF, with -80 dBm
threshold, 60 s scans, 8 dB hysteresis and 120 s dwell; scans are asynchronous, limited
to twelve displayed entries and inhibited during critical activity. HT20 is default;
HT40 is configurable and separately reports requested/effective state and application
success. RF performance, reconnect, roaming and scheduling measurements remain TO_TEST.

HWCDC in installed Arduino ESP32 3.3.11 cannot establish a trusted service-session
opening from `isConnected()`, DTR or SOF activity. AUTO/ON preferences therefore both
resolve to **NO_SLEEP**, just like OFF. The pure policy supports trusted session facts,
but the current adapter never manufactures them. AP/provisioning and OTA force OFF.

### Recovery AP and offline interface

Protected AP name is `MATDOG-<last six STA MAC hex digits>` (e.g. `MATDOG-227594`),
address `192.168.4.1/24`. There is no default password or admin token. Before first use,
a separately authorized physical USB session must provision a unique WPA2 passphrase
(8–63 characters) and a random 64-hex admin token; the token is stored as SHA-256 only.
No credentials were provisioned during this development task. Without an AP key no AP
is opened. AP appears on demand, without STA credentials, after repeated failures or
under the permanent policy. Timeout is 15 min, and only expires with working STA,
no clients and no transaction. Permanent AP must be disabled in configuration before
an OFF request can take effect. Shared AP/STA radio can change AP channel on association.

The embedded HTML has Dashboard, Wi-Fi, Access Point, Performance, OTA and Diagnostics;
it needs no CDN, Internet, asset server or actuator action. GET telemetry is sanitized;
SSID/BSSID/channel/RSSI, profiles, scans, config phase, heap, stack and timing are visible.
Password fields are write-only. Blank retains the existing password for the same SSID;
a changed SSID requires an explicit password. Open-network enrollment is not exposed
by this first portal. AP changes require a working STA and apply after the last AP
client disconnects, with `ap_reload_pending` reported until then.

HTTP port 80 serves the local portal. Writes require the actual AP socket, Host and
Origin `http://192.168.4.1`, admin login, random HttpOnly/SameSite cookie, CSRF token,
peer binding and 5-minute session lifetime. Login is throttled. Forms have a 1536-byte
bound and reject duplicate/unknown fields, malformed encodings and invalid addresses.
AP HTTP relies on the private WPA2 link; other holders of that AP passphrase share its
trust boundary. It is not a LAN-wide cleartext administration interface.

### Network configuration ownership

`NetworkConfigNvs` uses standard partition **nvs**, namespace **md_net_v1**, keys
**active/pending**. The fixed 512-byte record includes schema, magic and CRC32.
No initialization, erase, reset or migration occurs on corrupt/unsupported records;
writes lock on storage faults. `matdog_nvs` and calibration A/B/save markers remain
owned exclusively by the existing calibration backend. No diagnostic PHY erase was imported.

Web changes require a protected alternate AP path: CONFIG_PENDING → TESTING → COMMITTED
only after a fresh driver association to the chosen SSID and a valid IP. Old association
or stale IP cannot confirm a changed password. Timeout/critical state gives ROLLBACK to
known-good ACTIVE. PENDING is ignored at boot. The test confirms the chosen profile;
it does not claim that an untested secondary profile works. NVS flash operations are
on the worker, but flash cache stalls can still affect both cores: measure on hardware.

Read-only commands: `@WIFI STATUS`, `@WIFI PROFILES STATUS`, `@WIFI AP STATUS`,
`@WIFI SLEEP STATUS`, `@WIFI ROAM STATUS`, `@WIFI MODE STATUS`.
Authorized software intents: `@WIFI SCAN`, `@WIFI AP ON|OFF`, `@WIFI SLEEP AUTO|ON|OFF`,
`@WIFI ON|OFF` (OFF is temporary, 10 min), and physical USB provisioning
`@WIFI AP KEY <unique-passphrase>` / `@WIFI ADMIN KEY <random-64-hex-token>`.
QUEUED acknowledges an intent; inspect phase/status for completion. Malformed Wi-Fi
commands are redacted. Never paste real secrets into a recorded terminal/history.

See [V3 report](../../09_Logs/Validation_Reports/2026-10-04_WIFI_OTA_SHELLY_V3_OFFLINE.md)
and [hardware runbook](WIFI_OTA_SHELLY_HARDWARE_RUNBOOK.md).

## ActuatorAuthority

**Status: implemented, compiled, offline-tested. NOT hardware-tested.**

The single central arbiter of the exclusive right to **write** actuators. One instance exists,
owned by `Controller`; every other component holds a pointer and asks. `scripts/static_audit.py`
fails the build if a second instance appears or if any component caches the value.

### It is not a second OperatingMode

They are orthogonal axes and the distinction is load-bearing:

```text
OperatingMode       what the Controller as a whole is doing
                    MAINTENANCE: blocking diagnostics are safe
                    RUN:         a deterministic motion loop may be active

ActuatorAuthority   WHO, if anyone, currently holds the exclusive right to
                    issue actuator writes
```

A controller sits in `MAINTENANCE` with authority `NONE` indefinitely — that is the normal state
today, because **no write-capable owner exists yet**. The mode says what is safe; the authority
says who is doing it.

The compatibility table is enforced, not decorative:

| OperatingMode | may host |
|---|---|
| `MAINTENANCE` | `NONE`, `DIAGNOSTICS`, `CALIBRATION`, `QC`, `PROVISIONING` |
| `RUN` | `NONE`, `MOTION` |

A mode change that leaves the current owner incompatible **clears** it rather than leaving a
suspended authority. Today nothing can ever hold one, so this is a no-op — it exists so the first
real owner does not have to remember to add it. The table is the initial one and should be
re-reviewed when the motion loop lands and the `RUN` default flips.

### What it deliberately does not arbitrate

**Reads.** `@SERVO SCAN`, `@SERVO CENSUS` and `@SERVO READ` are `Ping`/`readByte`/`readWord`. They
are `MAINTENANCE`-gated because they **block**, not because they write, and they take no
authority. The arbiter exists to prevent write conflicts, not to serialize every read.

**`SAFE_OFF`.** A safety de-escalation must be reachable in every authority state, including an
inconsistent one. This is structural rather than a promise: `ServoBus` has no reference to the
arbiter and the arbiter has no reference to `ServoBus`, so `safeOff()` **cannot** consult an
authority even if a later edit wanted it to. The audit fails the build if the `@SERVO SAFE_OFF`
branch ever gains an authority or mode condition, or if `ServoBus` ever names one.

### Two semantics worth stating

**Same-owner re-request → `ALREADY_OWNED`, and no second lease.** Returning a second valid lease
would let two holders each believe they own it, and either could then release it out from under
the other. The existing holder keeps the only lease.

**Leases carry a generation.** Matching the owner alone already rejects "`CALIBRATION` releases
while `MOTION` holds". What it cannot catch is the same owner across two sessions:

```text
CALIBRATION acquires   (generation 1)
CALIBRATION releases
CALIBRATION acquires   (generation 2)
late callback from session 1 calls release(CALIBRATION)
    owner matches  ->  session 2 would be cleared out from under itself
```

The generation makes that release provably stale. It is refused and reported.

### No new write path

This phase implements the **arbiter**, not new capabilities. The firmware's only actuator write is
still `EnableTorque(id, 0)` inside `safeOff()`. Nothing can acquire an owner yet, and there is
deliberately **no command** that does — an operator-driven acquire would itself be a new write
path. `@AUTHORITY STATUS` is read-only.

### Exclusivity inhibit — and the TOCTOU problem it solves

Some activities are not actuator users but must exclude all of them. Firmware update is the first.
Adding an OTA entry to the owner enum would have been wrong twice over: OTA drives no actuator, and
it does not *compete* with `CALIBRATION` for a resource — it requires that **nobody** is using one.
The audit fails the build if such an entry is added.

The naive gate is genuinely insufficient:

```cpp
if (authority == NONE) { start OTA }     // not enough
```

Not because of threading — MATDOG's Controller is single-threaded, every subsystem runs
cooperatively inside `Controller::update()`, and nothing in MATDOG's own code owns a task or a
callback, so a check-then-act **inside one call** is already atomic. The hazard is **duration**: an
OTA update spans `prepare` → `openStream` → thousands of `writeChunk` calls → `finishStream` →
`commit`, across seconds of loop passes. Between any two of them a command can arrive and a future
`CalibrationManager` can acquire authority. No amount of re-checking closes that.

So the arbiter exposes a **hold**, not a query:

```text
requestInhibit(FIRMWARE_UPDATE)
    granted only when current() == NONE
    while held, every request() is REJECTED_INHIBITED
```

The "is anyone an owner?" check and the hold happen inside one arbiter call, so there is no window
between them. **No `SystemActivity` layer was needed**, and none was built.

A stuck inhibit is fail-safe: it blocks writes, it does not enable them. `forceClear()` of the
*owner* deliberately does not drop it — a fault must not quietly re-open actuator authority. It is
cleared explicitly, or by the next boot.

## Safe Actuator Layer

**Status (historical, 2026-09-25): policy core implemented, compiled, offline-tested. Runtime adapter TO_IMPLEMENT.
NO write path added.** *(Current: see [Calibration on `main`](#calibration-on-main-2026-09-29) —
bounded calibration was hardware-validated on 2026-10-01; operational motion remains blocked.)*

`src/actuator/ActuatorWritePolicy.*` is the boundary every future actuator write must pass
through. It is a **decision**, not a transport: there is no bus handle in it, so an `ACCEPT`
authorises nothing by itself.

**No "check once then write later".** `plan()` captures the `AuthorityLease`, the
`OperatingMode` and a policy epoch; `commit()` re-reads the live arbiter and compares all of it
again. Authority released and re-acquired, force-cleared, stranded by a mode change or overtaken
by an OTA inhibit each fail closed at commit. At most one transaction is outstanding, which is
what makes replay impossible rather than unlikely — a copy a caller kept is refused on identity
before its contents are read, and `reset()` advances the epoch so anything outstanding can never
match again.

**Limits are provenance first, value second.** A bound is usable only if
`calibration::mayPromote()` and `calibration::isOperationalEvidence()` both accept it and both
identity axes agree — the same test `q0MayBeAppliedTo()` applies. The store is empty and stays
empty: `MATDOG_JOINT_CALIBRATION.yaml` records `{min: null, max: null}` for all twelve leg
joints, so every position-class command resolves to `REJECT_NO_ACCEPTED_LIMITS`. A missing bound
is a refusal, never a fallback to a historical value.

**`SAFE_OFF` is outside this layer structurally.** There is no operation class for *removing*
torque, so a safety de-escalation is inexpressible here and no later edit can make it depend on
an authority check. For the same reason no persistent/provisioning write is expressible while
the repository still records that owner as `TO_DESIGN`.

The runtime adapter is deliberately **not** built yet: it would need a torque-on or
goal-position primitive, and both are prohibited by audits that exist for hardware-era reasons.
The full S0 write-surface map and the design rationale are in
[`SAFE_ACTUATOR_LAYER.md`](SAFE_ACTUATOR_LAYER.md).

### Calibration bootstrap — geometry-authorised moves

`src/actuator/CalibrationGeometryProfile.*` gives the Controller the compiled Geometry
Compiler V5 result as a generated `constexpr` table: **no JSON parser, no heap, no mesh and no
collision maths on the device**. It was produced by
`06_Software/Matdog_Core/calibration/matdog_calibration_geometry_export.py`, a pure reduction
of the canonical bundle that re-verifies every input hash and refuses to emit anything on
drift.

Three authorisation routes, mutually exclusive by construction:

| Operation | Authorised by |
|---|---|
| `POSITION_COMMAND` | accepted joint bounds — **unchanged, not weakened** |
| `DIRECTION_VERIFY` | the symmetric bootstrap envelope **and** the session's approved budget |
| `CALIBRATION_CONTACT_PROBE` | the endpoint plan **and** an accepted raw↔q transform |
| `CALIBRATION_AUXILIARY_MOVE` | the endpoint plan **and** an accepted raw↔q transform |

Three meanings are kept apart: a **geometric contact** is not an **executable target**, a
clearance **PASS** is not a **motion authorization**, and a **diagnostic endpoint** is not a
place the robot may be commanded to. Of 24 canonical endpoints only 8 are executable, and the
8 `UNRESOLVED` clearance verdicts all sit on diagnostic endpoints.

The direction-verify envelope is **symmetric and checked in tick space** — the magnitude of a
tick delta needs neither q0 nor direction, which is what makes the move that measures the sign
safe before the sign is known.

Everything failed closed at the time of writing: no q0 had been captured on the current
installation, so no transform existed and every plan-bound move refused. (Since 2026-09-27 a
read-only q0 capture has run on the robot, and 2026-09-29 promotes the current capture; the
plan-bound moves still refuse until a session, a promoted q0 and a fresh permit exist.) Audit and contract:
[`CALIBRATION_BOOTSTRAP.md`](CALIBRATION_BOOTSTRAP.md).

## OTA-A (update core)

**Status: implemented, compiled, offline-tested. NOT hardware-tested.** No MATDOG device has
received an OTA image. Nothing below is a claim about flash behaviour on real hardware.

OTA-A is the **update core only**. It ships **no transport** and **no authentication**, and
the byte-ingest entry points are compiled out by default. Nothing can feed it an image.

### Layering

```text
network transport                    NOT IMPLEMENTED in OTA-A (substitution point)
      |
      v
update/OtaManager                    Controller-facing owner + first-boot lifecycle
      |
      v
update/OtaPolicy                     the update state machine        (host-linkable)
update/OtaBootGuard                  the first-boot rollback guard   (host-linkable)
update/Sha256                        image identity                  (host-linkable)
      |
      v
OtaBackend (abstract)  ->  update/OtaEspBackend    the ONLY unit calling esp_ota_*
      |
      v
inactive OTA application slot
```

The backend is an interface rather than a direct `esp_ota_*` call so the offline suite drives
the **real** state machine against a fake backend that can fail any individual flash
operation. The logic under test is the shipped logic; only the flash is substituted.

### The one safety rule, made structural

OTA writes the **inactive** slot and only the inactive slot. That is not enforced by a comment:

- `esp_ota_get_next_update_partition(NULL)` is documented never to return the running
  partition — and `OtaPolicy` checks it against the running partition anyway;
- three checks are stated explicitly rather than inferred from a backend refusal:
  `target != running`, `subtype ∈ ota_0..ota_15`, `image_size ≤ target.size`;
- `OtaEspBackend::setBootPartition()` re-reads `esp_ota_get_running_partition()` and refuses
  independently, so the last line of defence does not depend on `OtaPolicy` being correct;
- `commitBootTarget()` is the **only** method that changes the boot target, it has exactly
  one `setBootPartition(` call site, and it is callable from exactly one state.

`scripts/flash_app_only.sh` is **not** reused as the OTA writer. It deliberately writes the
**active** slot over USB — it is a wired service/recovery path with different guarantees, and
its logic was audited for reuse, not adopted.

### State machine

```text
IDLE ──prepare()──► TARGET_RESOLVED ──openStream()──► RECEIVING ──finishStream()──┐
  ▲                        │                             │                        │
  │                        │                             │                   IMAGE_SEALED
  │                        │                             │                        │
  │                        ▼                             ▼                        ▼
  └──── abort()/reset() ──── FAILED ◄──────────────────────────────────  IDENTITY_VERIFIED
                               ▲                                                  │
                    boot target NEVER touched                          commitBootTarget()
                                                                                  │
                                                                                  ▼
                                                                        BOOT_TARGET_SET
```

Each of the distinctions that matter is a separate observable fact: update not started
(`IDLE`), target resolved but no flash touched (`TARGET_RESOLVED`), stream open and writing
(`RECEIVING` + `bytes_written`), stream incomplete (`INCOMPLETE_STREAM`, caught by *our*
byte count before the backend is even asked), `esp_ota_end` outcome (`IMAGE_SEALED` vs
`IMAGE_REJECTED`), image identity (`IDENTITY_VERIFIED` vs `HASH_MISMATCH`), boot target not
yet changed (every state except the last), boot target changed (`BOOT_TARGET_SET`).

### Five kinds of verification, kept distinct

They are not synonyms, and only the third can tell "a valid image" from "the expected image":

| Layer | What it proves | Who does it |
|---|---|---|
| transport integrity | the declared number of bytes arrived | `OtaPolicy` byte accounting |
| image validity | the bytes form a loadable app image | `esp_ota_end()` |
| cryptographic hash identity | the bytes are **the** expected bytes | `Sha256` vs declared digest |
| firmware/build identity | which commit this image came from | `build::kBuildId` in metadata |
| bootloader validity | which slot boots, and its rollback state | otadata / `esp_ota_get_state_partition` |

Metadata reuses the identity scheme the repository already has — `build::kBuildId`, plus the
`APPLICATION_SHA256` and `APPLICATION_SIZE` that `scripts/build_manifest.py` already records.
No second version scheme was invented.

It deliberately does **not** use `esp_app_desc_t`. Parsing the real built binary shows why:

```text
version      = 'ee57070'              <- the arduino-lib-builder commit
project_name = 'arduino-lib-builder'  <- not MATDOG
date/time    = 'Jul 20 2026'          <- when the prebuilt libs were built
```

Those fields describe the core, not this firmware, so they cannot answer "is this the
firmware I expected?".

### First-boot validation and rollback

The real build has `CONFIG_BOOTLOADER_APP_ROLLBACK_ENABLE=y` (read from the generated
`sdkconfig`, not assumed). That makes **never confirming the safe default**: the bootloader
moves a `PENDING_VERIFY` entry to `ABORTED` on the next boot and falls back to the other
slot, with no code of ours involved. Confirming early throws that safety net away for exactly
the case it exists for.

So confirmation is **earned by running**. `esp_ota_mark_app_valid_cancel_rollback()` is called
only after all of these hold, and `scripts/static_audit.py` fails the build if
`Controller::begin()` ever confirms an image:

```text
Controller::begin() ran to COMPLETION     (the flag is its last statement)
CommandRouter is bound and usable
firmware identity is readable             (running slot is an OTA slot, build id present)
this boot did NOT follow PANIC/INT_WDT/TASK_WDT/WDT/BROWNOUT
uptime >= 15 s
completed loop ticks >= 2000
```

Uptime alone would be satisfied by a controller wedged in one long call; ticks alone by a
fast boot loop. Both are required, and both are finite and deterministic.

A refusal deliberately does **not** call the invalidate-and-reboot API. Refusing is already
sufficient, and rebooting a robot is not OTA-A's decision to make. An explicit, authorized
operator rollback is **TO_IMPLEMENT / OTA-B**.

**Provisional until ActuatorAuthority exists:** these criteria contain no servo, DALY, IMU or
motion condition — deliberately, because peripheral presence is not evidence about firmware
and making it one would roll back a perfectly good image because a cable was unplugged. When
the authority model lands, the question of whether confirmation should additionally require a
safe actuator state is **TO_DESIGN**.

### OTA-B authorization — implemented

`src/update/OtaAuthorityGate.*` is the definitive gate, backed by the real
[ActuatorAuthority](#actuatorauthority) arbiter. The OTA-A placeholder is **gone**, not kept
alongside; the audit fails the build if its names reappear.

OTA never becomes an actuator owner — it drives no actuator, and it does not compete with
`CALIBRATION` for a resource, it requires that nobody is using one. It takes an **exclusivity
inhibit** instead, and it takes it as a *hold* rather than a *query*, because an update spans
seconds of loop passes and a query can only be true about the instant it ran. The reasoning and
the TOCTOU analysis are in the
[exclusivity inhibit](#exclusivity-inhibit--and-the-toctou-problem-it-solves) section.

```text
prepare()            -> beginExclusive() -> requestInhibit(FIRMWARE_UPDATE)
                        granted only when authority == NONE
during the update    -> every request() is REJECTED_INHIBITED
failure/abort/reset  -> endExclusive(), so a failed update never leaves the
                        robot permanently unable to calibrate
successful commit    -> hold KEPT until the reboot: a boot switch is pending,
                        and calibrating against an image about to be replaced
                        is not something to permit for convenience
```

The policy still **fails closed** with no gate installed, and now also with a gate whose arbiter
was never bound. Remaining for OTA-B: an explicit, authorized operator rollback.

### V3 transport and security — 2026-10-04

HTTP OTA challenge/upload are refused. `esp_https_server` provides an optional STA-only
443 listener, backed by a unique per-device PEM certificate/private key from gitignored
`src/config/TlsIdentity.local.h`. The distributed candidate has no identity or HMAC
secret. The listener requires quiet MAINTENANCE, persisted network/admin configuration
and a 100 KB largest internal heap block; one socket, 28 KB task stack and a 5 s
handshake timeout bound resources. These settings are provisional, not a hardware TLS
qualification. Losing eligibility shuts down the listener outside an active safe stream.

The existing `OtaSession` challenge/HMAC protocol and
`OtaManager → OtaPolicy → OtaEspBackend` remain the single firmware writer. No
ArduinoOTA, Update.h or portal writer was introduced. Metadata size/hash/build ID,
nonce expiry/single use, partition identity, authority inhibit and first-boot rollback
remain enforced. Timeout, truncated stream and link loss abort; hash/finalization failure
never requests a new boot target. Success remains COMMITTED_PENDING_REBOOT, with the
actuator inhibit held. **Authenticated remote reboot is BLOCKED / unimplemented** in V1;
no endpoint calls restart and there is no implicit reboot.

Source and final artifacts keep `MATDOG_OTA_INGEST_ENABLED=0`. Enabling ingest requires
separate hardware acceptance of TLS resources, USB recovery, calibration baseline,
authenticated explicit reboot and OTA/rollback gates. Offline linking of a disposable
TLS identity does not authorize that override or deployment.

`scripts/ota_tls_client.py` defaults to offline package verification. It requires a
full independently checked source SHA, CLEAN manifest, exact image/hash/FQBN/profile,
layout/table hash and ESP32-S3 identity. Explicit upload additionally requires CA+SAN
verification and an independently provisioned DER certificate SHA256 pin, checked on
every connection, plus the HMAC secret. It never disables TLS verification, follows
redirects, resumes an old nonce/session or automatically reboots. The manifest is a
provenance check, not an image signing PKI. No uploader operation was run on a device.

### Resource cost

Historical I7 measurement (2026-09-25; superseded for the V3 resource budget):

```text
flash       959,043 B -> 967,915 B   (+8,872 B)   30% of the 3 MB slot
static RAM   50,868 B ->  51,676 B   (+808 B)     15%
```

No image is ever held in RAM: bytes are hashed and written per chunk, and the chunk buffer
belongs to the transport. `esp_ota_begin()` uses `OTA_WITH_SEQUENTIAL_WRITES` so the erase is
incremental per sector instead of a single up-front ~1 MB erase that would stall the loop for
seconds.

**Flash erase and write do block the Controller loop.** That is a property of SPI flash, not
something a comment can fix. `@OTA STATUS` reports the measured worst case
(`open_us`/`write_us`/`end_us`), so the OTA-B integration can argue from numbers. Those
numbers do not exist yet — they require a hardware test.

## Anti-back-power (LED ring)

The WS2812B ring's 5V rail is physically absent under `USB_ONLY`
(`build::kLedRailPowered == false`). `LedRing::begin()` sets GPIO47 to `INPUT` and
never calls into `Adafruit_NeoPixel` — no WS2812 frame is ever transmitted toward the
unpowered ring, including via `@LED TEST` (refused with `REASON=LED_RAIL_UNPOWERED`).
`LedRing::dataPinDriven()` lets `@LED STATUS`/tests confirm this held for the whole
session. Since G2, `kLedRailPowered` is no longer independently editable: it and the two
other rail flags are derived from the selected hardware profile (see Hardware profile
above), and `static_audit.py` asserts both that they stay derived and that the
compiled-in default profile remains `USB_ONLY`.
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

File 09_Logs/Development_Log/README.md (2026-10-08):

# Development Log — index

Chronological handoffs and milestone records. A log states what was current **on its date**; its
"next steps" are historical. Status of a result is whatever the log itself records for its scope; this
index adds no status of its own. Current state: [root README](../../README.md). Whole-project
chronology: [`HISTORY_INDEX.md`](../HISTORY_INDEX.md).

Titles are quoted from each file (some are in Italian). Controller V0.1 / G2 / G3 history for
2026-09-01 – 2026-09-19 has no dated log here; it is recorded in
[`VALIDATION.md`](../../05_Firmware/MATDOG_Controller/VALIDATION.md) (Sessions 1, 2, 2.1, 2.2, dated
2026-09-15) and in the [ROADMAP](../../01_Docs/02_Architecture/ROADMAP.md). The checkpoint file
[`2026-10-03_M0_4_P1_CHECKPOINT.json`](2026-10-03_M0_4_P1_CHECKPOINT.json) accompanies the
M0.4 P1 closure log.
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

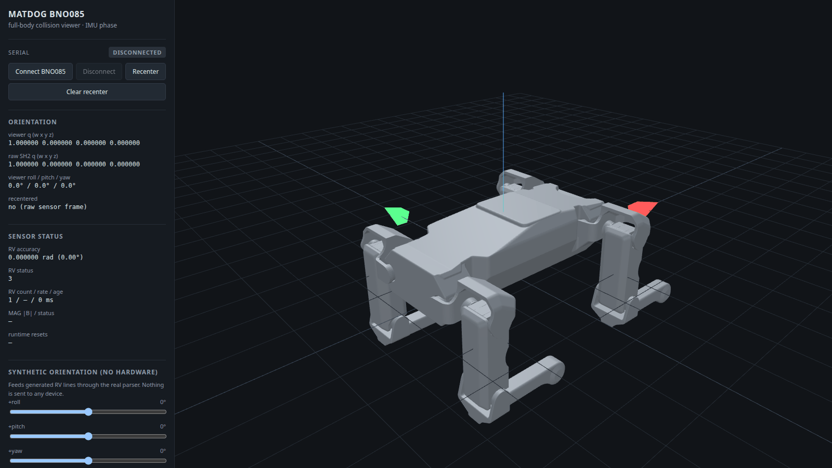
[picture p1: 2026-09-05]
06_Software/Matdog_Core/viewer/matdog_bno085_fullbody_viewer/docs/viewer-preview.png

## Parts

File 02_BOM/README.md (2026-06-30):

# MATDOG Bill of Materials

This directory contains the bill of materials and component records for MATDOG.

## Scope

- actuators
- electronics
- mechanical components
- fasteners
- sensors
- batteries and power electronics
- manufacturing consumables
- supplier references and costs

## Current Status

The mechanical and electronic architecture is still evolving.

The canonical kinematic mass and material references for the current robot body and legs are stored in:

[MATDOG REV00 reference workbook](../03_CAD/URDF/matt_robodog_rev00/reference/Coordinate_Cinematiche_matt_robodog_rev00.xlsx)

That workbook is not a procurement BOM. It is the engineering reference for link masses, materials and kinematic components.

## Future Structure

This directory will contain versioned BOM files when the following subsystems are frozen:

- mechanical assembly
- servo and wiring system
- power system
- battery and BMS
- head and sensor package
- onboard computing hardware

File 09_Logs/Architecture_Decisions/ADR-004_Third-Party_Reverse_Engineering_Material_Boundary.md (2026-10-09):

# ADR-004 — Third-party reverse-engineering material stays out of MATDOG history

Date: 2026-10-08

## Status

Accepted (owner decision for PR-2, 2026-10-08; applied unchanged to PR-3). Does not supersede ADR-001 to ADR-003.

## Context

MATDOG research on the XGO Lite quadruped produced static-analysis material: decompiler text
extracted from a third-party firmware image and values derived from it. The research has its own
repository, `MattRobotics/xgolite-low-level-reconstruction`. That repository states that
vendor code, firmware packages and third-party material whose redistribution is not appropriate
are not to be committed, and that clean-room specifications stay separate from vendor code.

Neither repository contains a licence or an authorization that covers redistributing the
firmware-derived material. The `LICENSE` of `robot-dog` (MIT, Matt Robotics 2026) covers MATDOG's
own work only. That material was nevertheless committed to branches of `robot-dog` on
2026-09-29 and 2026-10-05, so it is already in the history of several public branches. It is not
on `main`.

## Decision

1. `main` does not receive: the 38 `xgo_static_extracts/` text files, the XGO trace, table,
   catalogue, revision-comparison and search-inventory JSON files, any other artifact derived from
   the firmware that has not been reviewed, or copies that reproduce them.
2. Provenance of excluded material is recorded by reference (repository, commit, path, SHA-256),
   never by content. The manifest `motion_integration_manifest_pr2.json` lists them as `DEFERRED`.
3. Integration from the Integration dev.1 line (PR-2) and from the dev.2/dev.3 line (PR-3) is
   selective. In PR-2, history up to the boundary commit `13da04a` is merged with its original
   SHAs; later commits are recreated as new commits. In PR-3 all seven commits are recreated. A
   recreated commit carries the original SHA in its message and leaves the third-party material
   out.
4. No automatic merge, cherry-pick or import from the reverse-engineering repository into
   `robot-dog`. MATDOG-original results enter only after a provenance and independence review.
5. A MATDOG component that really needs an excluded artifact is `DEFERRED` or `BLOCKED`. Tests are
   not weakened to hide this.

## Consequences

- The pure motion library (`src/motion`) is on `main`, unwired. Its execution suites, oracles and
  the G35/G4/G4.1/G5-A evidence are not: they are `DEFERRED`, not deleted. They remain on the
  preserved branches.
- Deleting a file from `main` later would not remove it from Git history; this is why the
  boundary is enforced at integration time.
- The material that is already public on other branches is a separate exposure. Handling it
  (including any history change) is an owner decision outside this ADR and is not performed here.
- Re-admitting deferred material needs verifiable authorization or a clean-room regeneration, and
  its own review.

## Application in PR-3

The seven dev.2/dev.3 commits descend from `3f23439`, so they are recreated as new commits whose
parent is `main` (full `Original-SHA:` in each message). Each delta was applied as a patch
(`git cherry-pick --no-commit`) and committed anew; no original commit becomes an ancestor of
`main`. Their deltas contain no excluded artifact. The PR-2 manifest, the DEFERRED declaration and the source/purity/wiring gate
are unchanged.

## Verification

The PR-2 gate `run_motion_convergence_tests.py` fails if any `DEFERRED` path is present in the
tree. The Git object closure of PR-2 was checked against the blob hashes of the excluded files
(0 reachable).

## Status update (2026-10-09)

Annotation only; the decision above is unchanged and the boundary is not weakened. The historical GitHub
branches that held the excluded material have been deleted. While Draft PR #42 is open its working branch
`docs/c2-final-sync` also exists; the target is `main` alone after it is merged and that branch is deleted. `main`, the 9 tags
and the 41 pull-request refs reach none of the 284 known excluded blobs. Deleting the branches does not
guarantee removal of material that was public before: it may persist in GitHub storage, caches, forks and
clones. The original commits are kept in a non-public archive (owner-reported) and must not be pushed to a
public ref. Details: [`EXTERNAL_ARCHIVES.md`](../EXTERNAL_ARCHIVES.md). Any further handling remains an
owner decision.

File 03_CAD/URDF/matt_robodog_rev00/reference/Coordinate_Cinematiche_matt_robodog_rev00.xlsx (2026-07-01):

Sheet: Joint_Parameters
MATDOG — matt_robodog_rev00 | Tabella cinematica canonica
Baseline URDF consolidata · origini joint nel frame del parent link · mesh auditata · limiti in gradi e radianti
Robot | matt_robodog_rev00 | Revisione | REV00 — Kinematics lower limit -92° | Stato | CANONICA — CLEAN AUDIT | Total joints | 16 | Revolute | 12 | Fixed | 4
Leg | Joint | Parent link | Child link | Type | Motor ID | Dir | Axis X | Axis Y | Axis Z | X parent [mm] | Y parent [mm] | Z parent [mm] | θ min [deg] | θ max [deg] | X parent [m] | Y parent [m] | Z parent [m] | θ min [rad] | θ max [rad] | Speed [rpm] | Speed [rad/s] | Torque [kg·cm] | Effort [N·m]
LF | lf_hip_joint | base_link | lf_hip_link | Revolute | 13 | 1 | 1 | 0 | 0 | 112.5 | 47.5 | 46.5 | -45.0 | 45.0 | 0.1125 | 0.0475 | 0.0465 | -0.7853981634 | 0.7853981634 | 29.0 | 3.036873 | 9.2 | 0.902244
LF | lf_upper_leg_joint | lf_hip_link | lf_upper_leg_link | Revolute | 12 | 1 | 0 | 1 | 0 | 0.0 | 48.0 | 0.0 | -52.5 | 122.5 | 0.0000 | 0.0480 | 0.0000 | -0.9162978573 | 2.1380283337 | 29.0 | 3.036873 | 9.2 | 0.902244
LF | lf_lower_leg_joint | lf_upper_leg_link | lf_lower_leg_link | Revolute | 11 | 1 | 0 | 1 | 0 | 0.0 | 0.0 | -90.0 | -92.0 | 37.5 | 0.0000 | 0.0000 | -0.0900 | -1.6057029118 | 0.6544984695 | 29.0 | 3.036873 | 9.2 | 0.902244
LF | lf_foot_joint | lf_lower_leg_link | lf_foot_link | Fixed |  |  |  |  |  | 107.0 | -1.5 | -49.9
RF | rf_hip_joint | base_link | rf_hip_link | Revolute | 23 | 1 | 1 | 0 | 0 | 112.5 | -47.5 | 46.5 | -45.0 | 45.0 | 0.1125 | -0.0475 | 0.0465 | -0.7853981634 | 0.7853981634 | 29.0 | 3.036873 | 9.2 | 0.902244
RF | rf_upper_leg_joint | rf_hip_link | rf_upper_leg_link | Revolute | 22 | -1 | 0 | 1 | 0 | 0.0 | -48.0 | 0.0 | -52.5 | 122.5 | 0.0000 | -0.0480 | 0.0000 | -0.9162978573 | 2.1380283337 | 29.0 | 3.036873 | 9.2 | 0.902244
RF | rf_lower_leg_joint | rf_upper_leg_link | rf_lower_leg_link | Revolute | 21 | -1 | 0 | 1 | 0 | 0.0 | 0.0 | -90.0 | -92.0 | 37.5 | 0.0000 | 0.0000 | -0.0900 | -1.6057029118 | 0.6544984695 | 29.0 | 3.036873 | 9.2 | 0.902244
RF | rf_foot_joint | rf_lower_leg_link | rf_foot_link | Fixed |  |  |  |  |  | 107.0 | 1.5 | -49.9
RH | rh_hip_joint | base_link | rh_hip_link | Revolute | 33 | -1 | 1 | 0 | 0 | -112.5 | -47.5 | 26.5 | -45.0 | 45.0 | -0.1125 | -0.0475 | 0.0265 | -0.7853981634 | 0.7853981634 | 29.0 | 3.036873 | 9.2 | 0.902244
RH | rh_upper_leg_joint | rh_hip_link | rh_upper_leg_link | Revolute | 32 | -1 | 0 | 1 | 0 | 0.0 | -48.0 | 0.0 | -52.5 | 122.5 | 0.0000 | -0.0480 | 0.0000 | -0.9162978573 | 2.1380283337 | 29.0 | 3.036873 | 9.2 | 0.902244
RH | rh_lower_leg_joint | rh_upper_leg_link | rh_lower_leg_link | Revolute | 31 | -1 | 0 | 1 | 0 | 0.0 | 0.0 | -90.0 | -92.0 | 37.5 | 0.0000 | 0.0000 | -0.0900 | -1.6057029118 | 0.6544984695 | 29.0 | 3.036873 | 9.2 | 0.902244
RH | rh_foot_joint | rh_lower_leg_link | rh_foot_link | Fixed |  |  |  |  |  | 107.0 | 1.5 | -49.9
LH | lh_hip_joint | base_link | lh_hip_link | Revolute | 43 | -1 | 1 | 0 | 0 | -112.5 | 47.5 | 26.5 | -45.0 | 45.0 | -0.1125 | 0.0475 | 0.0265 | -0.7853981634 | 0.7853981634 | 29.0 | 3.036873 | 9.2 | 0.902244
LH | lh_upper_leg_joint | lh_hip_link | lh_upper_leg_link | Revolute | 42 | 1 | 0 | 1 | 0 | 0.0 | 48.0 | 0.0 | -52.5 | 122.5 | 0.0000 | 0.0480 | 0.0000 | -0.9162978573 | 2.1380283337 | 29.0 | 3.036873 | 9.2 | 0.902244
LH | lh_lower_leg_joint | lh_upper_leg_link | lh_lower_leg_link | Revolute | 41 | 1 | 0 | 1 | 0 | 0.0 | 0.0 | -90.0 | -92.0 | 37.5 | 0.0000 | 0.0000 | -0.0900 | -1.6057029118 | 0.6544984695 | 29.0 | 3.036873 | 9.2 | 0.902244
LH | lh_foot_joint | lh_lower_leg_link | lh_foot_link | Fixed |  |  |  |  |  | 107.0 | -1.5 | -49.9

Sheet: Mesh_Transforms
MATDOG — Mesh visual + collision + proprietà dinamiche · STL mm → URDF m
Origini mesh visual/collision: xyz = 0,0,0 m · rpy = 0°,0°,0°. Gli STL CAD restano in millimetri; ogni <mesh> URDF applica scale="0.001 0.001 0.001".
Link | Visual mesh | Collision mesh | Visual X [m] | Visual Y [m] | Visual Z [m] | Visual R [deg] | Visual P [deg] | Visual Yaw [deg] | Collision X [m] | Collision Y [m] | Collision Z [m] | Collision R [deg] | Collision P [deg] | Collision Yaw [deg] | Mass [g] | Mass [kg] | Engineering material / composition | Weight roll-up components | Fastener allocation | CoM status | Inertia status | URDF metadata | Visual scale [STL → URDF] | Collision scale [STL → URDF] | STL source unit | URDF geometry unit
base_link | meshes/base_link.stl | meshes/base_link.stl | 0.0000 | 0.0000 | 0.0000 | 0.0 | 0.0 | 0.0 | 0.0000 | 0.0000 | 0.0000 | 0.0 | 0.0 | 0.0 | 1282.0000 | 1.2820 | CAD physical-property report | physprop__base_link.txt + weight_breakdown_summary.txt | CoM available | Tensor available | URDF <inertial> inserted | Simulation-ready · mesh scale=0.001 | 0.001 0.001 0.001 | 0.001 0.001 0.001 | mm | m
lf_hip_link | meshes/lf_hip_link.stl | meshes/lf_hip_link.stl | 0.0000 | 0.0000 | 0.0000 | 0.0 | 0.0 | 0.0 | 0.0000 | 0.0000 | 0.0000 | 0.0 | 0.0 | 0.0 | 50.0000 | 0.0500 | CAD physical-property report | physprop__lf_hip_link.txt + weight_breakdown_summary.txt | CoM available | Tensor available | URDF <inertial> inserted | Simulation-ready · mesh scale=0.001 | 0.001 0.001 0.001 | 0.001 0.001 0.001 | mm | m
lf_upper_leg_link | meshes/lf_upper_leg_link.stl | meshes/lf_upper_leg_link.stl | 0.0000 | 0.0000 | 0.0000 | 0.0 | 0.0 | 0.0 | 0.0000 | 0.0000 | 0.0000 | 0.0 | 0.0 | 0.0 | 172.5000 | 0.1725 | CAD physical-property report | physprop__lf_upper_leg_link.txt + weight_breakdown_summary.txt | CoM available | Tensor available | URDF <inertial> inserted | Simulation-ready · mesh scale=0.001 | 0.001 0.001 0.001 | 0.001 0.001 0.001 | mm | m
lf_lower_leg_link | meshes/lf_lower_leg_link.stl | meshes/lf_lower_leg_link.stl | 0.0000 | 0.0000 | 0.0000 | 0.0 | 0.0 | 0.0 | 0.0000 | 0.0000 | 0.0000 | 0.0 | 0.0 | 0.0 | 59.5000 | 0.0595 | CAD physical-property report | physprop__lf_lower_leg_link.txt + weight_breakdown_summary.txt | CoM available | Tensor available | URDF <inertial> inserted | Simulation-ready · mesh scale=0.001 | 0.001 0.001 0.001 | 0.001 0.001 0.001 | mm | m
lf_foot_link | meshes/lf_foot_link.stl | meshes/lf_foot_link.stl | 0.0000 | 0.0000 | 0.0000 | 0.0 | 0.0 | 0.0 | 0.0000 | 0.0000 | 0.0000 | 0.0 | 0.0 | 0.0 | 17.5000 | 0.0175 | CAD physical-property report | physprop__lf_foot_link.txt + weight_breakdown_summary.txt | CoM available | Tensor available | URDF <inertial> inserted | Simulation-ready · mesh scale=0.001 | 0.001 0.001 0.001 | 0.001 0.001 0.001 | mm | m
rf_hip_link | meshes/rf_hip_link.stl | meshes/rf_hip_link.stl | 0.0000 | 0.0000 | 0.0000 | 0.0 | 0.0 | 0.0 | 0.0000 | 0.0000 | 0.0000 | 0.0 | 0.0 | 0.0 | 50.0000 | 0.0500 | CAD physical-property report | physprop__lf_hip_link.txt + weight_breakdown_summary.txt | CoM available | Tensor available | URDF <inertial> inserted | Simulation-ready · mesh scale=0.001 | 0.001 0.001 0.001 | 0.001 0.001 0.001 | mm | m
rf_upper_leg_link | meshes/rf_upper_leg_link.stl | meshes/rf_upper_leg_link.stl | 0.0000 | 0.0000 | 0.0000 | 0.0 | 0.0 | 0.0 | 0.0000 | 0.0000 | 0.0000 | 0.0 | 0.0 | 0.0 | 172.5000 | 0.1725 | CAD physical-property report | physprop__lf_upper_leg_link.txt + weight_breakdown_summary.txt | CoM available | Tensor available | URDF <inertial> inserted | Simulation-ready · mesh scale=0.001 | 0.001 0.001 0.001 | 0.001 0.001 0.001 | mm | m
rf_lower_leg_link | meshes/rf_lower_leg_link.stl | meshes/rf_lower_leg_link.stl | 0.0000 | 0.0000 | 0.0000 | 0.0 | 0.0 | 0.0 | 0.0000 | 0.0000 | 0.0000 | 0.0 | 0.0 | 0.0 | 59.5000 | 0.0595 | CAD physical-property report | physprop__lf_lower_leg_link.txt + weight_breakdown_summary.txt | CoM available | Tensor available | URDF <inertial> inserted | Simulation-ready · mesh scale=0.001 | 0.001 0.001 0.001 | 0.001 0.001 0.001 | mm | m
rf_foot_link | meshes/rf_foot_link.stl | meshes/rf_foot_link.stl | 0.0000 | 0.0000 | 0.0000 | 0.0 | 0.0 | 0.0 | 0.0000 | 0.0000 | 0.0000 | 0.0 | 0.0 | 0.0 | 17.5000 | 0.0175 | CAD physical-property report | physprop__lf_foot_link.txt + weight_breakdown_summary.txt | CoM available | Tensor available | URDF <inertial> inserted | Simulation-ready · mesh scale=0.001 | 0.001 0.001 0.001 | 0.001 0.001 0.001 | mm | m
rh_hip_link | meshes/rh_hip_link.stl | meshes/rh_hip_link.stl | 0.0000 | 0.0000 | 0.0000 | 0.0 | 0.0 | 0.0 | 0.0000 | 0.0000 | 0.0000 | 0.0 | 0.0 | 0.0 | 50.0000 | 0.0500 | CAD physical-property report | physprop__lf_hip_link.txt + weight_breakdown_summary.txt | CoM available | Tensor available | URDF <inertial> inserted | Simulation-ready · mesh scale=0.001 | 0.001 0.001 0.001 | 0.001 0.001 0.001 | mm | m
rh_upper_leg_link | meshes/rh_upper_leg_link.stl | meshes/rh_upper_leg_link.stl | 0.0000 | 0.0000 | 0.0000 | 0.0 | 0.0 | 0.0 | 0.0000 | 0.0000 | 0.0000 | 0.0 | 0.0 | 0.0 | 172.5000 | 0.1725 | CAD physical-property report | physprop__lf_upper_leg_link.txt + weight_breakdown_summary.txt | CoM available | Tensor available | URDF <inertial> inserted | Simulation-ready · mesh scale=0.001 | 0.001 0.001 0.001 | 0.001 0.001 0.001 | mm | m
rh_lower_leg_link | meshes/rh_lower_leg_link.stl | meshes/rh_lower_leg_link.stl | 0.0000 | 0.0000 | 0.0000 | 0.0 | 0.0 | 0.0 | 0.0000 | 0.0000 | 0.0000 | 0.0 | 0.0 | 0.0 | 59.5000 | 0.0595 | CAD physical-property report | physprop__lf_lower_leg_link.txt + weight_breakdown_summary.txt | CoM available | Tensor available | URDF <inertial> inserted | Simulation-ready · mesh scale=0.001 | 0.001 0.001 0.001 | 0.001 0.001 0.001 | mm | m
rh_foot_link | meshes/rh_foot_link.stl | meshes/rh_foot_link.stl | 0.0000 | 0.0000 | 0.0000 | 0.0 | 0.0 | 0.0 | 0.0000 | 0.0000 | 0.0000 | 0.0 | 0.0 | 0.0 | 17.5000 | 0.0175 | CAD physical-property report | physprop__lf_foot_link.txt + weight_breakdown_summary.txt | CoM available | Tensor available | URDF <inertial> inserted | Simulation-ready · mesh scale=0.001 | 0.001 0.001 0.001 | 0.001 0.001 0.001 | mm | m
lh_hip_link | meshes/lh_hip_link.stl | meshes/lh_hip_link.stl | 0.0000 | 0.0000 | 0.0000 | 0.0 | 0.0 | 0.0 | 0.0000 | 0.0000 | 0.0000 | 0.0 | 0.0 | 0.0 | 50.0000 | 0.0500 | CAD physical-property report | physprop__lf_hip_link.txt + weight_breakdown_summary.txt | CoM available | Tensor available | URDF <inertial> inserted | Simulation-ready · mesh scale=0.001 | 0.001 0.001 0.001 | 0.001 0.001 0.001 | mm | m
lh_upper_leg_link | meshes/lh_upper_leg_link.stl | meshes/lh_upper_leg_link.stl | 0.0000 | 0.0000 | 0.0000 | 0.0 | 0.0 | 0.0 | 0.0000 | 0.0000 | 0.0000 | 0.0 | 0.0 | 0.0 | 172.5000 | 0.1725 | CAD physical-property report | physprop__lf_upper_leg_link.txt + weight_breakdown_summary.txt | CoM available | Tensor available | URDF <inertial> inserted | Simulation-ready · mesh scale=0.001 | 0.001 0.001 0.001 | 0.001 0.001 0.001 | mm | m
lh_lower_leg_link | meshes/lh_lower_leg_link.stl | meshes/lh_lower_leg_link.stl | 0.0000 | 0.0000 | 0.0000 | 0.0 | 0.0 | 0.0 | 0.0000 | 0.0000 | 0.0000 | 0.0 | 0.0 | 0.0 | 59.5000 | 0.0595 | CAD physical-property report | physprop__lf_lower_leg_link.txt + weight_breakdown_summary.txt | CoM available | Tensor available | URDF <inertial> inserted | Simulation-ready · mesh scale=0.001 | 0.001 0.001 0.001 | 0.001 0.001 0.001 | mm | m
lh_foot_link | meshes/lh_foot_link.stl | meshes/lh_foot_link.stl | 0.0000 | 0.0000 | 0.0000 | 0.0 | 0.0 | 0.0 | 0.0000 | 0.0000 | 0.0000 | 0.0 | 0.0 | 0.0 | 17.5000 | 0.0175 | CAD physical-property report | physprop__lf_foot_link.txt + weight_breakdown_summary.txt | CoM available | Tensor available | URDF <inertial> inserted | Simulation-ready · mesh scale=0.001 | 0.001 0.001 0.001 | 0.001 0.001 0.001 | mm | m
Nota di allocazione: i 4 g di fasteners misurati per ciascuna zampa sono assegnati provvisoriamente all’hip link per preservare il totale reale di 316 g/leg. Questa è una convenzione di massa per link; i baricentri e le inerzie verranno poi sostituiti con proprietà CAD misurate.

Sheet: Reference_Notes
MATDOG — Riferimento cinematica REV00
Documento | Coordinate Cinematiche — Canonical
Robot | matt_robodog_rev00
File URDF finale | matt_robodog_rev00.urdf
Stato | Baseline cinematica + dinamica + scala mesh approvata
Convenzioni di riferimento
1 | Frame robot ROS | X avanti · Y sinistra · Z alto · sistema destrorso.
2 | Origine joint | Ogni xyz di joint è espresso nel frame del parent link.
3 | Frame mesh | Ogni origin di visual/collision è espresso nel frame del link.
4 | Collisione attuale | Stessa mesh STL della visuale: valida per verifica geometrica; non ancora ottimizzata per fisica.
5 | Assi cinematici | Hip: +X · Upper/Lower: +Y · Fixed foot: nessun asse.
6 | Unità URDF | Metri · radianti · rad/s · N·m.
7 | Unità mesh STL | Vertici STL esportati dal CAD in mm. In ogni mesh visual e collision URDF: scale="0.001 0.001 0.001"; joint, CoM e inerzie restano in unità SI.
Correzioni finali incorporate in questa revisione
✓ | lh_hip_joint | X = -112.5 mm: nodo posteriore sinistro corretto.
✓ | upper_leg_joint (×4) | Limiti corretti: θmin = -52.5° · θmax = +122.5°.
✓ | lower_leg_joint (×4) | Limiti corretti: θmin = -92.0° · θmax = +37.5°.
✓ | Mesh origins (tutti i link) | Visual + collision: xyz = 0, 0, 0 m · rpy = 0°, 0°, 0°.
✓ | foot_joint (×4) | Nomi corretti: joint fisso tra lower_leg_link e foot_link.
Proprietà dinamiche REV00
1 | Masse per link | Masse CAD riconciliate: totale 17-link = 2.480 kg. Vedi Mass_Reconciliation.
2 | Centro di massa | CoM per-link importati dal CAD in metri, espressi nel frame locale URDF.
3 | Inerzia | Tensori al CoM ricostruiti da assi principali + raggi di girazione CAD e inseriti come blocchi <inertial>.
4 | Validazione | Somma 17 link: massa uguale all’assieme CAD; errore massimo CoM 0.374 mm rispetto al report assembly.
5 | Neck yaw actuator | Nessun link separato in REV00: non è stato aggiunto senza un report CAD della sua posa montata.

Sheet: Link_Engineering
MATDOG — Proprietà fisiche per link URDF
Masse, CoM e inerzie dinamiche sono ora definite dal CAD. Il foglio Inertial_Properties è la sorgente canonica dei valori URDF; Engineering_Weight_Source resta un confronto storico.
Link | Zone | URDF mesh | Mass [g] | Mass [kg] | Assembly grouping | Material composition | Components from Engineering_Data | Fastener allocation | Inertial status | URDF status
base_link | Body | meshes/base_link.stl | 1282.0000 | 1.2820 | CAD physical-property subassembly | Mass reconciliation + Solid Edge report | physprop__base_link.txt + weight_breakdown_summary.txt | Direct CAD | CoM + inertia tensor reconstructed at CoM | Standard URDF <inertial> inserted
lf_hip_link | LF | meshes/lf_hip_link.stl | 50.0000 | 0.0500 | CAD physical-property subassembly | Mass reconciliation + Solid Edge report | physprop__lf_hip_link.txt + weight_breakdown_summary.txt | Direct CAD | CoM + inertia tensor reconstructed at CoM | Standard URDF <inertial> inserted
lf_upper_leg_link | LF | meshes/lf_upper_leg_link.stl | 172.5000 | 0.1725 | CAD physical-property subassembly | Mass reconciliation + Solid Edge report | physprop__lf_upper_leg_link.txt + weight_breakdown_summary.txt | Direct CAD | CoM + inertia tensor reconstructed at CoM | Standard URDF <inertial> inserted
lf_lower_leg_link | LF | meshes/lf_lower_leg_link.stl | 59.5000 | 0.0595 | CAD physical-property subassembly | Mass reconciliation + Solid Edge report | physprop__lf_lower_leg_link.txt + weight_breakdown_summary.txt | Direct CAD | CoM + inertia tensor reconstructed at CoM | Standard URDF <inertial> inserted
lf_foot_link | LF | meshes/lf_foot_link.stl | 17.5000 | 0.0175 | CAD physical-property subassembly | Mass reconciliation + Solid Edge report | physprop__lf_foot_link.txt + weight_breakdown_summary.txt | Direct CAD | CoM + inertia tensor reconstructed at CoM | Standard URDF <inertial> inserted
rf_hip_link | RF | meshes/rf_hip_link.stl | 50.0000 | 0.0500 | CAD physical-property subassembly | Mass reconciliation + Solid Edge report | physprop__lf_hip_link.txt + weight_breakdown_summary.txt | LF symmetry-derived | CoM + inertia tensor reconstructed at CoM | Standard URDF <inertial> inserted
rf_upper_leg_link | RF | meshes/rf_upper_leg_link.stl | 172.5000 | 0.1725 | CAD physical-property subassembly | Mass reconciliation + Solid Edge report | physprop__lf_upper_leg_link.txt + weight_breakdown_summary.txt | LF symmetry-derived | CoM + inertia tensor reconstructed at CoM | Standard URDF <inertial> inserted
rf_lower_leg_link | RF | meshes/rf_lower_leg_link.stl | 59.5000 | 0.0595 | CAD physical-property subassembly | Mass reconciliation + Solid Edge report | physprop__lf_lower_leg_link.txt + weight_breakdown_summary.txt | LF symmetry-derived | CoM + inertia tensor reconstructed at CoM | Standard URDF <inertial> inserted
rf_foot_link | RF | meshes/rf_foot_link.stl | 17.5000 | 0.0175 | CAD physical-property subassembly | Mass reconciliation + Solid Edge report | physprop__lf_foot_link.txt + weight_breakdown_summary.txt | LF symmetry-derived | CoM + inertia tensor reconstructed at CoM | Standard URDF <inertial> inserted
rh_hip_link | RH | meshes/rh_hip_link.stl | 50.0000 | 0.0500 | CAD physical-property subassembly | Mass reconciliation + Solid Edge report | physprop__lf_hip_link.txt + weight_breakdown_summary.txt | LF symmetry-derived | CoM + inertia tensor reconstructed at CoM | Standard URDF <inertial> inserted
rh_upper_leg_link | RH | meshes/rh_upper_leg_link.stl | 172.5000 | 0.1725 | CAD physical-property subassembly | Mass reconciliation + Solid Edge report | physprop__lf_upper_leg_link.txt + weight_breakdown_summary.txt | LF symmetry-derived | CoM + inertia tensor reconstructed at CoM | Standard URDF <inertial> inserted
rh_lower_leg_link | RH | meshes/rh_lower_leg_link.stl | 59.5000 | 0.0595 | CAD physical-property subassembly | Mass reconciliation + Solid Edge report | physprop__lf_lower_leg_link.txt + weight_breakdown_summary.txt | LF symmetry-derived | CoM + inertia tensor reconstructed at CoM | Standard URDF <inertial> inserted
rh_foot_link | RH | meshes/rh_foot_link.stl | 17.5000 | 0.0175 | CAD physical-property subassembly | Mass reconciliation + Solid Edge report | physprop__lf_foot_link.txt + weight_breakdown_summary.txt | LF symmetry-derived | CoM + inertia tensor reconstructed at CoM | Standard URDF <inertial> inserted
lh_hip_link | LH | meshes/lh_hip_link.stl | 50.0000 | 0.0500 | CAD physical-property subassembly | Mass reconciliation + Solid Edge report | physprop__lf_hip_link.txt + weight_breakdown_summary.txt | LF symmetry-derived | CoM + inertia tensor reconstructed at CoM | Standard URDF <inertial> inserted
lh_upper_leg_link | LH | meshes/lh_upper_leg_link.stl | 172.5000 | 0.1725 | CAD physical-property subassembly | Mass reconciliation + Solid Edge report | physprop__lf_upper_leg_link.txt + weight_breakdown_summary.txt | LF symmetry-derived | CoM + inertia tensor reconstructed at CoM | Standard URDF <inertial> inserted
lh_lower_leg_link | LH | meshes/lh_lower_leg_link.stl | 59.5000 | 0.0595 | CAD physical-property subassembly | Mass reconciliation + Solid Edge report | physprop__lf_lower_leg_link.txt + weight_breakdown_summary.txt | LF symmetry-derived | CoM + inertia tensor reconstructed at CoM | Standard URDF <inertial> inserted
lh_foot_link | LH | meshes/lh_foot_link.stl | 17.5000 | 0.0175 | CAD physical-property subassembly | Mass reconciliation + Solid Edge report | physprop__lf_foot_link.txt + weight_breakdown_summary.txt | LF symmetry-derived | CoM + inertia tensor reconstructed at CoM | Standard URDF <inertial> inserted

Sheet: Mass_Summary
MATDOG — Riepilogo masse REV00
Baseline dinamica CAD: 17 link, 2.480 kg. Il dettaglio della riconciliazione tra CAD, calcolo pesi e misura fisica è nel foglio Mass_Reconciliation.
Metric | Value
URDF modeled links mass [g] | 2480.0000
URDF modeled links mass [kg] | 2.4800
Four legs mass [g] | 1198.0000
Base link mass [g] | 1282.0000
CAD full assembly [g] | 2480.0000
Weight-breakdown calculated [g] | 2389.4000
Physical robot measured [g] | 2297.0000
Neck yaw actuator [g] | 61.0000
Standalone neck yaw link in REV00 | No
Dynamic property status | CAD CoM + inertia tensor inserted

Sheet: Engineering_Weight_Source
Engineering_Data.xlsx — Historical weight source / reconciliation input
Historical component allocation retained for traceability. It is not the dynamic source of truth: masses and inertias now come from Solid Edge physical-property exports plus the CAD mass reconciliation in Inertial_Properties and Mass_Reconciliation.
N. | Subsystem | Component | Side | Material | Interasse (mm) | Q.ty | Weight (g) | Notes | URDF link allocation
1 | Actuator / Motor | ACT_FL_Shoulder_11 | FL | - |  | 1 | 61.0 | ID_motor:11 | lf_hip_link
2 | Leg | Shoulder_Joint_L | FL | PPA+CF |  | 1 | 32.0 |  | lf_hip_link
3 | Actuator / Motor | ACT_FL_UpperLeg_12 | FL | - |  | 1 | 61.0 | ID_motor:12 | lf_upper_leg_link
4 | Leg | Upper_Leg | FL | PPA+CF |  | 1 | 32.0 |  | lf_upper_leg_link
5 | Leg | Upper_Leg_Cover | fl | ABS ESD |  | 1 | 5.0 |  | lf_upper_leg_link
6 | Actuator / Motor | ACT_FL_LowerLeg_13 | FL | - |  | 1 | 61.0 | ID_motor:13 | lf_lower_leg_link
7 | Leg | Lower_Leg_L | FL | PPA+CF |  | 1 | 53.5 |  | lf_lower_leg_link
8 | Leg | Rubber_Foot | FL | TPU 95A |  | 1 | 6.5 |  | lf_foot_link
9 | Fastners |  | FL | Steel |  | 1 | 4.0 |  | lf_hip_link
 |  |  |  |  |  | Tot.: | 316.0
10 | Actuator / Motor | ACT_FR_Shoulder_21 | FR | - |  | 1 | 61.0 | ID_motor:21 | rf_hip_link
11 | Leg | Shoulder_Joint_R | FR | PPA+CF |  | 1 | 32.0 |  | rf_hip_link
12 | Actuator / Motor | ACT_FR_UpperLeg_22 | FR | - |  | 1 | 61.0 | ID_motor:22 | rf_upper_leg_link
13 | Leg | Upper_Leg | FR | PPA+CF |  | 1 | 32.0 |  | rf_upper_leg_link
14 | Leg | Upper_Leg_Cover | FR | ABS ESD |  | 1 | 5.0 |  | rf_upper_leg_link
15 | Actuator / Motor | ACT_FR_LowerLeg_23 | FR | - |  | 1 | 61.0 | ID_motor:23 | rf_lower_leg_link
16 | Leg | Lower_Leg_R | FR | PPA+CF |  | 1 | 53.5 |  | rf_lower_leg_link
17 | Leg | Rubber_Foot | FR | TPU 95A |  | 1 | 6.5 |  | rf_foot_link
18 | Fastners |  | FR | Steel |  | 1 | 4.0 |  | rf_hip_link
 |  |  |  |  |  | Tot.: | 316.0
19 | Actuator / Motor | ACT_RR_Shoulder_31 | RR | - |  | 1 | 61.0 | ID_motor:31 | rh_hip_link
20 | Leg | Shoulder_Joint_R | RR | PPA+CF |  | 1 | 32.0 |  | rh_hip_link
21 | Actuator / Motor | ACT_RR_UpperLeg_32 | RR | - |  | 1 | 61.0 | ID_motor:32 | rh_upper_leg_link
22 | Leg | Upper_Leg | RR | PPA+CF |  | 1 | 32.0 |  | rh_upper_leg_link
23 | Leg | Upper_Leg_Cover | RR | ABS ESD |  | 1 | 5.0 |  | rh_upper_leg_link
24 | Actuator / Motor | ACT_FR_LowerLeg_33 | RR | - |  | 1 | 61.0 | ID_motor:33 | rh_lower_leg_link
25 | Leg | Lower_Leg_R | RR | PPA+CF |  | 1 | 53.5 |  | rh_lower_leg_link
26 | Leg | Rubber_Foot | RR | TPU 95A |  | 1 | 6.5 |  | rh_foot_link
27 | Fastners |  | RR | Steel |  | 1 | 4.0 |  | rh_hip_link
 |  |  |  |  |  | Tot.: | 316.0
28 | Actuator / Motor | ACT_RL_Shoulder_41 | RL | - |  | 1 | 61.0 | ID_motor:41 | lh_hip_link
29 | Leg | Shoulder_Joint_L | RL | PPA+CF |  | 1 | 32.0 |  | lh_hip_link
30 | Actuator / Motor | ACT_RL_UpperLeg_42 | RL | - |  | 1 | 61.0 | ID_motor:42 | lh_upper_leg_link
31 | Leg | Upper_Leg | RL | PPA+CF |  | 1 | 32.0 |  | lh_upper_leg_link
32 | Leg | Upper_Leg_Cover | RL | ABS ESD |  | 1 | 5.0 |  | lh_upper_leg_link
33 | Actuator / Motor | ACT_RL_LowerLeg_43 | RL | - |  | 1 | 61.0 | ID_motor:43 | lh_lower_leg_link
34 | Leg | Lower_Leg_L | RL | PPA+CF |  | 1 | 53.5 |  | lh_lower_leg_link
35 | Leg | Rubber_Foot | RL | TPU 95A |  | 1 | 6.5 |  | lh_foot_link
36 | Fastners |  | RL | Steel |  | 1 | 4.0 |  | lh_hip_link
 |  |  |  |  |  | Tot.: | 316.0
37 | Chassis / Body | Lower_Chassis | - | PPA+CF |  | 1 | 283.0 |  | base_link
38 | Fastners |  |  | Steel |  | 1 | 2.0 |  | base_link
39 | Actuator / Motor | ACT_HD_Base_Yaw_51 | CN | - |  | 1 | 61.0 | ID_motor:41 | Not in REV00 URDF (future neck/head link)
 |  |  |  |  |  | Tot.: | 1610.0

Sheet: URDF_Audit
MATDOG — Audit URDF REV00 con proprietà dinamiche
Audit aggiornato: struttura, joint, mesh, scala STL mm→m, limiti, masse CAD, CoM per-link e tensori d’inerzia.
Area | Esito | Dettaglio | Azione | Stato
Struttura | PASS | 17 link · 16 joint · singola root: base_link. | Nessuna. | Pulito
Catene cinematiche | PASS | 4 catene complete: hip → upper → lower → foot. | Nessuna. | Pulito
Coordinate joint | PASS | Tutti gli origin joint sono nel parent-link frame; rpy joint = 0. | Nessuna. | Pulito
Lower leg limits | PASS | 4 joint: θmin = -92° (-1.605702911835 rad) · θmax = +37.5°. | Aggiornati nella presente revisione. | Canonico
Upper leg limits | PASS | 4 joint: θmin = -52.5° · θmax = +122.5°. | Nessuna. | Canonico
Mesh references | PASS | 34 riferimenti mesh (visual + collision), tutti relativi a meshes/*.stl; 17 asset unici; ogni mesh dichiara scale="0.001 0.001 0.001". | Scala URDF dichiarata per STL CAD in mm. | Canonico
Mesh origins | PASS | 17 link: visual e collision usano xyz 0,0,0 · rpy 0,0,0. | Nessuna. | Pulito
Visual / Collision | PASS | Per ciascun link visual e collision usano stessa mesh e stessa origin. | Scelta attuale conservata. | Coerente
Masses + CoM | PASS | 2.480 kg from CAD reconciliation; every modeled link has a CAD CoM in its local URDF frame. | Inserted in standard <inertial> blocks. | Simulation-ready
Inertia tensors | PASS | Tensors reconstructed at CoM from principal axes + radii of gyration; symmetry-derived legs aggregate-check against full CAD assembly. | Inserted in standard <inertial> blocks. | Simulation-ready
Neck yaw scope | INFO | No standalone neck yaw link or mounted-frame inertial report is included in REV00. | Keep excluded until dedicated CAD export is available. | Controlled scope
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

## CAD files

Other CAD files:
03_CAD/URDF/matt_robodog_rev00/meshes/collision/lf_upper_leg_link.stl
03_CAD/URDF/matt_robodog_rev00/meshes/collision/lh_lower_leg_link.stl
03_CAD/URDF/matt_robodog_rev00/meshes/collision/rh_upper_leg_link.stl
03_CAD/URDF/matt_robodog_rev00/meshes/collision/lf_hip_link.stl
03_CAD/URDF/matt_robodog_rev00/meshes/collision/rf_upper_leg_link.stl
03_CAD/URDF/matt_robodog_rev00/meshes/collision/rf_hip_link.stl
03_CAD/URDF/matt_robodog_rev00/meshes/collision/lh_hip_link.stl
03_CAD/URDF/matt_robodog_rev00/meshes/collision/lf_foot_link.stl
03_CAD/URDF/matt_robodog_rev00/meshes/collision/lf_lower_leg_link.stl
03_CAD/URDF/matt_robodog_rev00/meshes/collision/rf_lower_leg_link.stl
03_CAD/URDF/matt_robodog_rev00/meshes/collision/base_link.stl
03_CAD/URDF/matt_robodog_rev00/meshes/collision/lh_upper_leg_link.stl
03_CAD/URDF/matt_robodog_rev00/meshes/collision/lh_foot_link.stl
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

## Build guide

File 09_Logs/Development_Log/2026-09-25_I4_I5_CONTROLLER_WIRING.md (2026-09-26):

# I4/I5 — Controller wiring: fail-closed infrastructure integration

**Date:** 2026-09-25 · **Branch:** `feat/controller-nextgen-integration-v1`

Per the operator's objective-change instruction: wire `ActuatorRuntime` and `CalibrationExecutionEngine`
into `Controller` as status/lifecycle infrastructure, without making Torque ON, `GoalPosition`,
contact motion or calibration motion reachable.

## What changed

`Controller` now owns real instances of `actuator::SafeActuatorPolicy`, `actuator::ActuatorRuntime`
and `calibration::CalibrationExecutionEngine` — previously none of the three existed inside
`Controller` at all; they were exercised only by their own offline test suites. `Controller::begin()`
wires them:

```cpp
actuator_policy_.begin(&authority_);
actuator_runtime_.begin(&actuator_policy_, /*backend=*/nullptr);
calibration_execution_.begin(&actuator_policy_, &actuator_runtime_);
```

Three deliberate choices make this safe:

1. **The runtime adapter's backend is `nullptr`.** Every `ActuatorRuntime::execute()` call that
   somehow reached an `ACCEPT` decision would still resolve to `ExecuteResult::NO_BACKEND` — there
   is nothing to write to, independent of policy state, geometry, or authority.
2. **No geometry is bound, no limit or transform is admitted, no live bootstrap context is set.**
   `actuator_policy_` starts and stays in exactly the state its own offline suite already proves is
   maximally restrictive: an empty limit table (`REJECT_NO_ACCEPTED_LIMITS`), no geometry
   (`REJECT_NO_GEOMETRY_PROFILE`), no transform (`REJECT_NO_ACCEPTED_TRANSFORM`).
3. **No command path calls `plan()`/`commit()`/`execute()`/`abort()`.** `ControllerService` exposes
   only read-only status (`epoch()`, `hasOutstandingTransaction()`, `counters()`, `lastDecision()`,
   `limits().size()`, `transforms().size()`, a geometry-bound boolean) — new `@ACTUATOR STATUS`
   presents it. No new write-capable command was added anywhere.

`ActuatorRuntime` and `CalibrationExecutionEngine` themselves expose no status of their own — both
are effectively stateless between calls neither of which `Controller` ever makes — so
`ControllerService` reads only from `SafeActuatorPolicy`, the layer both sit on top of.

## Boundary enforcement, and a real bug it caught

Both I4/I5 boundary checks (`check_actuator_runtime_boundaries`,
`check_calibration_execution_engine_boundaries`) were extended to allow `Controller.h`/`Controller.cpp`
as the one reviewed consumer, by exact filename — not by directory — so `CommandRouter.cpp` and
`ControllerService.h`, which also live in `src/core/`, remain excluded and cannot reference either
class by name.

New `check_actuator_infrastructure_wired_fail_closed()` enforces the three choices above
structurally:

- `actuator_runtime_.begin(...)` must contain the literal `nullptr`.
- `Controller.cpp` must never contain `bindGeometry(`, `.admit(`, or `setBootstrapContext(`.
- `CommandRouter.cpp`, `ControllerService.h` and `Controller.cpp` must never call
  `plan()`/`commit()`/`execute()`/`abort()`.

**The first version of the third rule was wrong and would not have caught a real violation.** It
checked for the literal substrings `".plan("`, `".commit("`, etc. — but `modules_.actuator_policy`
is a pointer, so every real call site uses `->plan(`, not `.plan(`. A manual mutation check
(temporarily injecting `modules_.actuator_policy->plan(...)` into `CommandRouter.cpp`) confirmed
`static_audit.py` still reported `PASS` with the dot-only check — a false negative, caught before
being trusted. Fixed to a regex matching both call syntaxes
(`(?:\.|->)\s*(plan|commit|execute|abort)\s*\(`), re-verified to catch the same injected call, then
re-verified clean after reverting. The equivalent `nullptr`-presence check was also manually
mutated-and-reverted to confirm it fires.

## Verification

- Offline suites: **14 host suites, 5726 checks** (unchanged — this gate is Arduino-only glue with
  no new pure logic; correctness rests on the static-audit boundary checks above plus the already-
  exhaustive `SafeActuatorPolicy`/`ActuatorRuntime`/`CalibrationExecutionEngine` suites).
- Static audit: **PASS, 89 files**, 0 findings, including both manually-verified mutation checks.
- `USB_ONLY`: PASS — 981,727 B flash (+2,616 B vs. the I6 baseline of 979,111 B — this code is no
  longer dead-code-eliminated, since `Controller` now genuinely calls into it), 53,356 B RAM
  (+872 B).
- `ROBOT_POWERED`: PASS — 982,299 B flash (+2,644 B vs. 979,655 B). Default `USB_ONLY` artifact
  restored afterward.

## Outcome

`I4`/`I5` Controller wiring complete. `hardware_motion_authorized` stays `0`; no accepted current
`JointTransform` means no raw target is ever computable; the runtime backend is `nullptr` so no
write is ever reachable even if every upstream check were somehow bypassed; `RESTORE` remains
categorically non-executing in `CalibrationExecutionEngine` (unchanged from I5, so authority loss
still produces zero restore motion); global `SAFE_OFF` remains completely independent of all three
new instances (`ServoBus::safeOff()` has no reference to any of them). Proceeding to `I8`.

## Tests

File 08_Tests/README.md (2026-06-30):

# MATDOG Tests

This directory contains repeatable tests, test scripts, fixtures and recorded outputs for MATDOG.

## Scope

- URDF structural validation
- mesh and frame validation
- joint-limit validation
- calibration checks
- forward-kinematics tests
- inverse-kinematics tests
- gait trajectory tests
- hardware safety checks
- Station compatibility tests

## Current Status

The first validated engineering baseline is:

    MATDOG URDF REV00

Its validation report is stored in:

    ../09_Logs/Validation_Reports/2026-06-30_URDF_REV00_Kinematic_Validation.md

## Test Development Order

    URDF structure
    → mechanical zero calibration
    → encoder-to-radian conversion
    → single-joint motion
    → single-leg FK
    → single-leg IK
    → stand pose
    → gait trajectory
    → hardware locomotion

Tests must be added before enabling automated multi-servo motion on the physical robot.

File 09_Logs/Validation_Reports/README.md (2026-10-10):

# Validation reports — index

Each entry is evidence for its recorded date and scope only. A PASS here does not carry over to a
later firmware, a later mechanical state or a later power architecture, and no entry authorizes
motion (`MOTION_AUTHORIZED=0`). Recorded PASS/FAIL results are not edited by this index.
Current state: [root README](../../README.md). Chronology: [`HISTORY_INDEX.md`](../HISTORY_INDEX.md).

Legend — **Era**: *Station* = Station-mediated, 12-servo phase (historical); *Rebuild* = after the
2026-08-27 rebuild (17 allocated servo slots, of which 13 are physically installed today: 12 leg + neck ID 51; ESP32-S3 Controller). **Kind**: HW = hardware evidence, OFFLINE =
software/model only.

## Model, kinematics and early hardware (June–July 2026)

| Report | Date | Kind | Era | Scope as recorded |
|---|---|---|---|---|
| [ST3215 Bus Validation](2026-06-17_ST3215_Bus_Validation.md) | 2026-06-17 | HW | Station, SUPERSEDED banner | Station-mediated ST3215 bus validation |
| [URDF REV00 Kinematic Validation](2026-06-30_URDF_REV00_Kinematic_Validation.md) | 2026-06-30 | OFFLINE | model | URDF topology, frames, axes, limits (see [ADR-003](../Architecture_Decisions/ADR-003_URDF_REV00_Kinematic_Baseline.md)) |
| [Visual-Zero and Static Actuation Validation](2026-07-06_Visual_Zero_and_Static_Actuation_Validation.md) | 2026-07-06 | HW | Station, SUPERSEDED banner | Visual-zero calibration and static actuation, 12-servo installation |
| [C4-A offline safe-stand candidate](2026-07-08_175245_C4A_offline_safe_stand_candidate.json) | 2026-07-08 | OFFLINE | model | Offline candidate; `command_eligible=false`. Path is globbed by kinematics tools: do not rename |
| C4 offline policy set — [collision/contact](C4_collision_contact_policy/), [rest-to-stand trajectory](C4_rest_to_stand_trajectory/), [timing envelope](C4_trajectory_timing_envelope/), [static stability](C4_static_stability_support_polygon/), [hardware safe-mode preflight](C4_hardware_safe_mode_preflight/) | 2026-07-08 | OFFLINE | model | C4-B…C4-F offline artifacts |
| [Geometry Compiler artifacts](Geometry_Compiler/README.md) | 2026-08-07 – 2026-08-11 | OFFLINE | model | v1–v5 geometry runs with per-run status and SHA-256 (index inside) |

## ST3215 bench phase (August 2026)

| Report | Date | Kind | Scope as recorded |
|---|---|---|---|
| [ST3215 Bench QC](ST3215_Bench_QC_2026-08-24/README.md) | 2026-08-24/25 | HW (bench) | 26/26 runs COMPLETE, protocol V6.1 |
| [ST3215 Provisioning](ST3215_Provisioning_2026-08-27/README.md) | 2026-08-27 | HW (bench) | Historical bench provisioning of 17 allocated units, 17/17 PASS. It does not imply that 17 servos are installed: 13 are installed today (12 leg + neck ID 51) |

Navigation for the whole ST3215 evidence set: [`ST3215_EVIDENCE_INDEX.md`](../ST3215_EVIDENCE_INDEX.md).

## Controller on the rebuilt robot (September–October 2026)

| Report | Date | Kind | Scope as recorded |
|---|---|---|---|
| [CR2-C current-installation q0 capture](Calibration_Q0_CR2C_2026-09-27/README.md) | 2026-09-27 | HW (read-only) | Read-only q0 capture, "CR2-C PASS"; does not accept or promote calibration |
| [Full Calibration sequence geometry](Full_Calibration_Sequence_Geometry_2026-09-30/README.md) | 2026-09-30 | OFFLINE | Nominal CAD mesh non-intersection, 24-contact sequence; no hardware |
| [TRUE Full Calibration 24/24](Full_Calibration_24_Contact_Hardware_2026-10-01/README.md) | 2026-10-01 | HW | 24/24 contacts, `all_contact_calibrated=1`, no operational envelope approved. Its statement "RAM-only" is correct for that session and firmware; for the later persistence work see the dev.3 audit below and [`OPEN_ITEMS.md`](../OPEN_ITEMS.md) |
| [Wi-Fi / provisioning / OTA V3 offline](2026-10-04_WIFI_OTA_SHELLY_V3_OFFLINE.md) | 2026-10-04 | OFFLINE | Offline qualification only. It names a local worktree and a branch that no longer exist; read it as historical |
| [dev.2 boot self-test delta audit](MATDOG_V0_2_DEV2_BOOT_SELFTEST_DELTA_AUDIT_2026-10-06.md) | 2026-10-06 | HW + audit | Boot census 13/13; calibration stopped at LF under dev.2 (block-read temperature artifact) |
| [dev.3 thermal delta audit](MATDOG_V0_2_DEV3_THERMAL_DELTA_AUDIT_2026-10-06.md) | 2026-10-06 | HW + audit | 24/24 under dev.3; SAVE/ACK and LOAD across a reset observed; automatic recovery not triggered; no real power cycle |
| [LED RMT DMA + dirty-frame hardware validation](MATDOG_LED_RMT_DMA_DIRTY_FRAME_HW_VALIDATION_2026-10-10.md) | 2026-10-10 | HW (LED only) | Installed `fee9383`: active RMT DMA, 10 min SoftAP-on steady LED without observed anomalies, servo timing unchanged; **no release or motion approval** |

## Not in this directory

- **Hardware Validation 2026-10-07 (dev.3):** execution COMPLETE, acceptance BLOCKED, as stated by
  the project owner. The full report is **not in the repository** and is not reconstructed here.
  See [`EXTERNAL_ARCHIVES.md`](../EXTERNAL_ARCHIVES.md).
- **Firmware offline test results** (PR-1, PR-2, PR-3 gates) are recorded in
  [`05_Firmware/MATDOG_Controller/VALIDATION.md`](../../05_Firmware/MATDOG_Controller/VALIDATION.md).
- **Controller V0.1, G2, G3 sessions** (2026-09-15, 2026-09-18) are recorded in the same
  `VALIDATION.md`, not as separate reports.
- **Motion G1–G5-A evidence** (G4, G4.1, G5-A, G35 pose audit) is deferred by
  [ADR-004](../Architecture_Decisions/ADR-004_Third-Party_Reverse_Engineering_Material_Boundary.md)
  and is not on `main`.

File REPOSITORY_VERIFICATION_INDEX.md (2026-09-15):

# MATDOG Geometry Compiler V5 verification record

> **HISTORICAL / REFERENCE — 2026-08-11 snapshot.**
>
> This file preserves the Phase 2A0 / Geometry Compiler V5 verification record. It does not define
> today's project status, physical population, immediate milestone, repository topology, or
> operational entry point. For those, use the [root `README.md`](README.md) and
> [`ARCHITECTURE.md`](01_Docs/02_Architecture/ARCHITECTURE.md).

**Recorded status on 2026-08-11:** Phase 2A0 CLOSED / Geometry Compiler V5 merged.

**Recorded next step on 2026-08-11:** Phase 2A — Generic V25-derived full-leg calibration engine.

These labels are retained as historical phase evidence, not as current instructions.

## Repository and source snapshot — 2026-08-11

```text
MattRobotics/robot-dog
  default branch: main
  post-Phase-2A0 merge baseline:
  f07aa094a1b78c5670cc36ef3fdb349422a38955
  role: robot-specific CAD / URDF / geometry / calibration evidence / project decisions

MattRobotics/norma-core
  default branch: main
  Phase 2A entry baseline observed 2026-08-11:
  f47b1ba579c623139058a8b0118648015739ab10
  role: Station/ST3215 runtime and native MATDOG calibrator

immutable LF V25 release:
  release/matdog-lf-calibrator-v25
  f87dd1fbc7e8100d275c74f9af448642f3429680
```

Always re-verify live remote/local state before implementation. The SHAs above are entry checkpoints, not permission to ignore newer legitimate commits.

## Phase state recorded on 2026-08-11

```text
Phase 1     CLOSED / historical endpoint-metrology candidate
Phase 1B    CLOSED
Phase 2A0   CLOSED / Geometry Compiler V5 merged via PR #19
Phase 2A    RECORDED NEXT (2026-08-11) / generic V25-derived full-leg engine
Phase 2B    pending / final path-parking safety integration
Phase 2C    pending / complete offline validation
hardware    later: RF -> RH -> LH
```

## Historical Phase 2A operational entry point

Recorded entry document:

```text
06_Software/Matdog_Core/calibration/
MATDOG_PHASE2A_GENERIC_V25_ENTRY_HANDOFF_2026-08-11.md
```

Phase 2A0 closeout record:

```text
09_Logs/Development_Log/
2026-08-11_PHASE2A0_GEOMETRY_V5_CLOSEOUT.md
```

Geometry Compiler artifact index:

```text
09_Logs/Validation_Reports/Geometry_Compiler/README.md
```

Within this snapshot, the older Phase1B-closed and 2026-08-07 calibration handoffs were
historical/architectural references rather than its Phase 2A milestone entry point.

## Geometry Compiler V5 canonical evidence record

Merged PR:

```text
robot-dog #19
reviewed head:
2890daf0a8ac6103d3856f208a5f042528fc0da0

squash merge commit on main:
f07aa094a1b78c5670cc36ef3fdb349422a38955
```

Corrected canonical semantic hashes:

```text
endpoint
  de205209f6015734f43af7f49146ecf60f89a74d6ce1276ce134c189a89c9f7e
parking
  67c58430e78241af1a636cdcc22092ff855371713fc7f26bc56412f7c7181139
combined
  0a772234a46afad14eb4af0999294020bb0fb8974ca0b68f3ccd780fa057db51
```

Corrected determinism manifests:

```text
C workers=1
b86b5d35678df4510989ea49fb5d42acaea2e4838226d7017456399dfceb0d81

D workers=4
0db86e633599f63a769dbba75db3a54c1e6470e128c007eb24c465f92a428b17
```

Final canonical evidence:

```text
24/24 geometric contacts
24/24 canonical contexts empty
24/24 endpoint/planner consistency
6 direct-target obstructions
18 collision-free direct paths

parking:
18 NOT_NEEDED
6 FEASIBLE_1DOF_PLAN_FOUND
24/24 complete sequences
94 evaluated 1DOF candidates
0 requiring 2DOF
```

Final tests:

```text
241/241 geometry discovery PASS
58/58 adjacent offline calibration PASS
299/299 total PASS
```

Independent adversarial review findings were all closed before merge:

```text
B1 CLOSED
M1 CLOSED
M2 CLOSED
M3 CLOSED
m1-m5 CLOSED
NO NEW BLOCKER / MAJOR
```

Permanent semantic boundary:

```text
CANONICAL V5 != G4 REPLAY
```

## External safety-policy state

Final reference policy uses the unchanged 3 mm threshold:

```text
16 PASS
0 FAIL
8 UNRESOLVED
0 motion authorizations
```

All eight `UNRESOLVED` are `DIAGNOSTIC_GEOMETRY_OUTSIDE_URDF_LIMITS`.

```text
lf_hip_joint:min
lf_lower_leg_joint:min
rf_hip_joint:max
rf_lower_leg_joint:min
rh_hip_joint:max
rh_lower_leg_joint:min
lh_hip_joint:min
lh_lower_leg_joint:min
```

There are zero FAIL and zero UNRESOLVED results among the eight `EXECUTABLE_URDF_DOMAIN` endpoints.

Never reinterpret:

```text
UNRESOLVED as PASS
DIAGNOSTIC as EXECUTABLE
GEOMETRIC CONTACT as MOTION AUTHORIZATION
```

These eight unresolved lower bounds remain explicit Phase 2B/2C inputs.

## Hardware calibration evidence in this historical snapshot

Only LF V25 is mechanically hardware validated.

```text
HIP   MIN -42.803°   MAX +39.375°
UPPER MIN -53.525°   MAX +122.607°
LOWER MIN -91.846°   MAX +34.277°
```

RF/RH/LH remain geometry-only until future hardware validation.

LF V25 must remain immutable. Older V28–V42 and duplicated all-leg/RF experiments are historical development evidence, not active programs.

## Recorded Phase 2A architecture contract — historical

Target:

```text
LegSessionStateMachine
+
LegCalibrationSpec
```

not four independent state machines.

Before refactoring LF V25, classify every materially relevant LF constant/helper/state transition:

```text
A — generic calibration behavior
B — geometry/profile/spec data
C — global ST3215 hardware/safety parameter
D — historical LF-only evidence
```

In this dated plan, Phase 2A was offline software foundation work. It authorized no physical
movement, Station probing, direct serial work, or EEPROM writes.

## Issues recorded for the planned next phase

1. Pre-existing live-FK calibration-status mismatch:
   `DIGITAL_ZERO_CALIBRATED_AND_VERIFIED` vs `VISUAL_ZERO_CAPTURED_PENDING_LIVE_VALIDATION`.
2. 16 diagnostic geometry targets outside operational URDF limits.
3. 8 unresolved conservative clearance lower bounds, all outside executable target domain.
4. RF/RH/LH lack hardware oracle evidence.
5. Do not copy LF measured spans as other-leg coordinates.
6. FRONT/HIND geometry is not interchangeable by convention.
7. A fitted affine diagnostic must never erase raw model-vs-hardware discrepancy.

## Records for this 2026-08-11 verification snapshot

Primary records at the time:

```text
README.md
REPOSITORY_VERIFICATION_INDEX.md
06_Software/Matdog_Core/calibration/MATDOG_PHASE2A_GENERIC_V25_ENTRY_HANDOFF_2026-08-11.md
09_Logs/Development_Log/2026-08-11_PHASE2A0_GEOMETRY_V5_CLOSEOUT.md
09_Logs/Validation_Reports/Geometry_Compiler/README.md
06_Software/Matdog_Core/calibration/MATDOG_LF_CALIBRATION_V25_FINAL.md
```

Earlier historical references retained at the time:

```text
06_Software/Matdog_Core/calibration/MATDOG_CALIBRATION_CANONICAL_HANDOFF_2026-08-07.md
06_Software/Matdog_Core/calibration/MATDOG_CALIBRATION_CANONICAL_HANDOFF_PHASE1B_CLOSED_2026-08-09.md
06_Software/Matdog_Core/calibration/MATDOG_GEOMETRY_COMPILER_PHASE1B_ADDENDUM_2026-08-08.md
```

Superseded Geometry Compiler candidate evidence remains preserved in its original validation-artifact locations and clearly labelled as superseded.

## Repository hygiene recorded at closeout

- Active development must start from verified current `main`, never from a merged historical branch.
- Merged/retired development branches may be deleted after their unique state is preserved by merged commits, PR history and a closeout log.
- Historical handoffs, validation artifacts and immutable releases must not be deleted merely to make the repository look cleaner.
- No force-push or destructive history rewrite.
- No merge into `main` without explicit authorization.

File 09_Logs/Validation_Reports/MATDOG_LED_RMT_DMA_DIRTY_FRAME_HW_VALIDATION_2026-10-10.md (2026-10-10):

# MATDOG — LED ring RMT DMA + dirty-frame: hardware validation (2026-10-10)

**Scope:** LED WS2812B transport only, no motion authorization and no general firmware/release acceptance.
**Provenance:** validated local firmware source commit `fee9383156fad914b03af27788c5519954e65fca` (parent `b3fd945bdaf37d192d97b605ac0f59b67f1dba45`). These historical commits are **not** imported as ancestors of public `main`; only the two LED source file blobs are selectively integrated.

## Firmware and installed image

- Installed and read-back verified: `ROBOT_POWERED`, `0.2.0-dev.3`, `build_id=fee9383156fa`, `GIT_DIRTY=NO`.
- Application SHA-256: `b3e2f01659fc4b03745616cfaf7185c747b3e98fc837f9d9b543e4af08e3bfc0`, 1,179,920 bytes.
- Active RMT transport at boot: **`LED_TRANSPORT=RMT_DMA`** on ESP32-S3 GPIO47, 12 WS2812B GRB pixels. The built candidate also has an explicit DMA-to-legacy fallback, not exercised in this successful run.
- The deployed image **is not** an image built from `main`. A rebuild from `main` produces a different Git provenance and build ID. **DO NOT FLASH MAIN**.

## Checks performed

| Gate | Observed result |
|---|---|
| Preflight | Prior dev.3 image `b3fd945bdaf3` identified; `READY / RUN / MAINTENANCE / NONE`; no actuation authorization |
| Full flash backup | 16 MiB read-only backup verified on the ASUS; **kept private, not committed or uploaded** |
| Flash | Official application-only flash and read-back verification **PASS**; no changes to bootloader, partition table, NVS, calibration, Wi-Fi or BMS |
| Boot | `LED_TRANSPORT=RMT_DMA`, IMU PASS, expected servo census **13/13**, calibration persistence `VALID_ACKNOWLEDGED`, BMS communications OK |
| LED observation | **10 minutes**, SoftAP active with **zero connected clients**, 6 steady green segments: **no observed spurious blue/red pixels, flashing or brightness jumps**; no reset or fallback to legacy |
| Three-servo scan | Median 17.5 ms vs historical dev.3 median 18 ms |
| Servo census 11..55 | 13 found, 920–927 ms vs 921–932 ms on dev.3 |
| Startup servo census | 4,007 ms vs prior 4,002–4,023 ms |
| Single-servo ping | Max 400 µs; gate 5,000 µs |
| Available heap | 162,636 B vs 166,092 B on dev.3 (DMA buffer overhead approximately 3.4 kB) |
| Offline gates | Static audit, full host suite, dirty-frame host and transport DMA host tests PASS; target compilation PASS |

## Limits of acceptance

- The LED-only behavior is **hardware-validated under the tested conditions**; the historical event rate before the update was not measured, so absence of a rare event is not statistically proven.
- The DMA and dirty-frame changes were deployed together; their individual effectiveness cannot be distinguished from this observation.
- No oscilloscope waveform was captured; real DMA-to-legacy fault fallback was not provoked.
- No movement or calibration-with-motion was performed or authorized. `MOTION_AUTHORIZED=0`, `RESTORE=NOT_IMPLEMENTED`.
- The AP portal HTTP 403 fix is **not present** in this installed LED candidate and remains a separate integration task.
- Private backup images and credential-bearing NVS dumps must not be published.

## Source integration policy

Public `main` receives only the firmware source contents of `src/status/LedRing.cpp` (Git blob `e3c7cfe8b1ade6976b8634127f510b615284ff84`) and `src/status/LedRing.h` (Git blob `0dd26b9402f16969f5057117f61b2af4c5d5a806`), plus documentation. No dev.3 history, third-party reverse-engineering extracts, image binaries or private backup artifacts are imported. Source equivalence is not equivalent to installed binary identity or to release acceptance.

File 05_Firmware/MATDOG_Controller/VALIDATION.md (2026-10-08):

# MATDOG Controller V0.1 — Validation

> **Reading guide (added 2026-10-08).** Sections are dated records; a result is valid for its own
> date, build and scope. The PR-2 and PR-3 sections at the top describe offline verification of what
> was integrated into `main`; they are not hardware results. Hardware results of the dev.2/dev.3
> candidate are in the [dev.2](../../09_Logs/Validation_Reports/MATDOG_V0_2_DEV2_BOOT_SELFTEST_DELTA_AUDIT_2026-10-06.md)
> and [dev.3](../../09_Logs/Validation_Reports/MATDOG_V0_2_DEV3_THERMAL_DELTA_AUDIT_2026-10-06.md)
> delta audits. The section "Present-day baseline and next gate" below is dated 2026-10-01. The
> chronology is in [`HISTORY_INDEX.md`](../../09_Logs/HISTORY_INDEX.md), the open items in
> [`OPEN_ITEMS.md`](../../09_Logs/OPEN_ITEMS.md).

## PR-3 dev.2/dev.3 source delta — offline verification, 2026-10-08

Scope: offline verification of the content PR-3 brings to `main` (seven recreated commits, see the
[PR-3 log](../../09_Logs/Development_Log/2026-10-08_PR3_DEV2_DEV3_SELECTIVE_INTEGRATION.md)).
**No hardware, serial, flash, NVS, EEPROM or OTA access. No hardware validation, no hardware
acceptance and no release acceptance of any `main` build.** `MOTION_AUTHORIZED=0`,
`RESTORE=NOT_IMPLEMENTED`. The layers stay apart:

| Layer | State |
|---|---|
| Code on `main` | PR-1, PR-2 and the dev.2 boot census, dev.3 thermal verdict, runner recovery, identity `0.2.0-dev.3` |
| Offline tests | the table below |
| Hardware results (historical, of the dev.2/dev.3 candidate on the robot) | in the [dev.2](../../09_Logs/Validation_Reports/MATDOG_V0_2_DEV2_BOOT_SELFTEST_DELTA_AUDIT_2026-10-06.md) and [dev.3](../../09_Logs/Validation_Reports/MATDOG_V0_2_DEV3_THERMAL_DELTA_AUDIT_2026-10-06.md) delta audits; not results for a `main` build |
| Hardware acceptance | dev.3 Hardware Validation 2026-10-07: execution COMPLETE, acceptance **BLOCKED**; its report is not in the repository |
| Release acceptance | none; no release approved |
| Deferred | motion execution suites, oracles and G35/G4/G4.1/G5-A evidence (unchanged from PR-2) |

Environment as for PR-2 (`arduino-cli` 1.5.1, `esp32:esp32` 3.3.11, pinned libraries, scipy, Git LFS
objects). Consolidated code tree `1d59dbe`; the later commits are Markdown only.

| Check | Result |
|---|---|
| `scripts/static_audit.py` (central gate, including the host and nested mutation suites) | **PASS** on the code tree; the run on the final tip is recorded in the PR description |
| Host suites inside the gate (47 result lines) | 0 failures; mutation suites detect their mutants |
| Motion source/purity/provenance gate | PASS; 44 integrated files and 34 inputs match their SHA-256; 286 deferred artifacts absent |
| Motion host tests, fresh oracles, audit-tool tests | **DEFERRED** — not run, not integrated |
| `MATDOG_PROFILE=USB_ONLY scripts/build.sh` | PASS; 1,174,320-byte application (22.4 % of the slot); `FW_VERSION=0.2.0-dev.3`; layout `MATDOG_16M_2x5M_NVS_V1`; table `8f756ecb…`; OTA ingest 0; manifest `SOURCE_STATE=CLEAN`, `SOURCE_COMMIT=1d59dbe…` |
| `MATDOG_PROFILE=ROBOT_POWERED scripts/build.sh` | PASS; 1,178,224 bytes (22.5 %); same version, layout, table, ingest and `SOURCE_STATE` |
| Compiler warnings | 2 per profile, both in the third-party SCServo library |

Source correspondence with dev.3 is by blob comparison (PR-3 log). It is not a binary claim: the
frozen dev.3 images recorded in the dev.3 audit are 1,178,272 bytes (ROBOT_POWERED) and 1,174,384
bytes (USB_ONLY), the container builds above are 48 and 64 bytes smaller. The cause was not
investigated, and the container binaries are not release artifacts and are not compared with the
installed image.

## PR-2 selective dev.1 integration — offline verification, 2026-10-08

Scope: offline verification of the content PR-2 brings to `main`. **No hardware, serial, flash, NVS,
EEPROM or OTA access. No hardware validation and no acceptance of a `main` build.**
`MOTION_AUTHORIZED=0`. The four layers are kept apart:

| Layer | State |
|---|---|
| Code integrated | boundary `13da04a` (13 original commits), three recreated commits, new gate manifest; see the [PR-2 log](../../09_Logs/Development_Log/2026-10-08_PR2_SELECTIVE_DEV1_INTEGRATION.md) |
| Offline tests | the table below |
| Hardware validated | nothing new from PR-2 |
| Deferred | the motion execution suites and the G35/G4/G4.1/G5-A evidence; reported as DEFERRED, never as passed |

Environment: cloud container with `arduino-cli` 1.5.1, `esp32:esp32` 3.3.11, the libraries pinned
in `SOURCE_PROVENANCE.md`, scipy, Git LFS objects. Code tree `44d72ee` (identical, outside
Markdown, to the final tip).

| Check | Result |
|---|---|
| `scripts/static_audit.py` (central gate, including host and nested mutation suites) | **PASS** on the code tree; the final-tip run is recorded in the PR description |
| `scripts/tests/run_host_tests.sh` | PASS, 33 suites, 0 failures |
| `run_motion_convergence_tests.py` (source, purity, dependency and wiring gate) | PASS: 44 integrated files and 34 canonical, retained and protected inputs match their SHA-256; no include of `motion/` outside `src/motion`; 286 deferred artifacts absent |
| Same gate with one deferred file added | FAIL, as intended |
| Motion host tests, fresh oracles, audit-tool tests | **DEFERRED** — not run, not integrated |
| `MATDOG_PROFILE=USB_ONLY scripts/build.sh` | PASS; 1,174,320-byte application (22.4 % of the slot); `FW_VERSION=0.2.0-dev.1`; layout `MATDOG_16M_2x5M_NVS_V1`; table `8f756ecb…`; OTA ingest 0; manifest `SOURCE_STATE=CLEAN` |
| `MATDOG_PROFILE=ROBOT_POWERED scripts/build.sh` | PASS; 1,177,856 bytes (22.5 %); same layout, table and ingest; `SOURCE_STATE=CLEAN` |
| Compiler warnings | 2 per profile, both in the third-party SCServo library |

Not claimed for `main`: the integration branch result of 2026-10-05/06 (20/20 motion qualification,
330/330 pinned files). Container binaries depend on the checkout path and are not release
artifacts. The hardware results for dev.2 and dev.3 belong to the dev.3 candidate and are in the
[dev.3 delta audit](../../09_Logs/Validation_Reports/MATDOG_V0_2_DEV3_THERMAL_DELTA_AUDIT_2026-10-06.md).
The 2026-10-07 Hardware Validation (execution COMPLETE, acceptance BLOCKED) has no report in this
repository yet.

## Wi-Fi / provisioning / OTA V3 — offline, 2026-10-04

Independent branch `feat/controller-wifi-ota-shelly-v1`, provisional base `1a5e008`.
See [V3 report](../../09_Logs/Validation_Reports/2026-10-04_WIFI_OTA_SHELLY_V3_OFFLINE.md)
for the matrix and [future hardware runbook](WIFI_OTA_SHELLY_HARDWARE_RUNBOOK.md).
Host configuration/security checks, real adapter with fake radio/NVS, TLS loopback,
HTTPS compile/link and offline DOM checks are recorded; final CLEAN USB_ONLY then
ROBOT_POWERED builds are bound to HEAD by the generated artifact receipt.
No hardware operation occurred. CAL_PERSIST_BASE is BLOCKED pending hardware evidence;
remote reboot is BLOCKED/unimplemented; ingest remains 0. No historical VALIDATED label
below applies automatically to this candidate.

Current-facing status vocabulary follows the canonical meanings in the root
[`README.md`](../../README.md#status-vocabulary): **VALIDATED**, **IMPLEMENTED**,
**DECIDED**, **TO_TEST**, **TO_DESIGN**, **FROZEN**, **SUPERSEDED**, and
**HISTORICAL**. Dated session evidence below preserves the status language that
was used when each session was recorded; it is not rewritten into present-day
terminology.

This document will be updated in place as hardware sessions progress; it is not
rewritten per session.

## Post-ABORT recovery and thermal acquisition — 2026-10-03

Status: **IMPLEMENTED**, verified offline; hardware validation **TO_TEST**.
The isolated branch `fix/calibration-post-abort-thermal` starts at `7b258b36c257`.
The original dirty checkout and gait branch are preserved. No controller port,
servo bus, reset, upload or flash was opened/executed in this task.

The focused regressions replay RF LOWER 2348/Q0 1997, RF UPPER 1080/Q0 2106,
RH UPPER 1665/Q0 2058, returning LOWER → UPPER → rear park, then all 12 Q0
and SAFE_OFF. They cover all four legs' UPPER/LOWER probe phases, unproven
HIP phases, unsafe dependencies, changed Q0, lost UART/permit, current,
real heat, timeouts, and observation while thermal confirmation is pending.
Thermal tests cover 95,117,34,34,34, true overheat, unavailable/invalid samples,
300 ms deadline and both concentrated and sparse repeated anomalies.
UART tests execute the actual validated transport against synthetic packets.
Native router/NVS and runner tests cover evidence retention, discard,
SAVE/ACK and simulated reboot. The report records final commands/results,
CAD sampling limits, release manifest and locally verified rollback evidence.

[Technical release report](../../09_Logs/Development_Log/2026-10-03_POST_ABORT_THERMAL_OFFLINE_RELEASE.md).
[Controlled future workflow and application-only update](POST_ABORT_RECOVERY_RUNBOOK.md).

## P3a.2 USB framing hardening — offline verification, 2026-10-02

Initial branch: `feat/calibration-persistence-record-store-v1`; initial HEAD:
`e82cdab9c58c3dadd512b993901303c9bc46fa39`. The worktree was clean before this task.
Production changes are limited to `src/core/CommandRouter.{h,cpp}`.

### Framing and reproductions

The unchanged 96-byte buffer accepts at most 95 payload bytes. LF dispatches a
valid nonempty line; CR is ignored, including when CRLF is split across updates.
The 96th payload byte or any NUL latches an error. The whole line is refused,
including the already collected prefix, and all subsequent bytes are discarded
through LF. The first error is reported once at LF; buffer, length and error are
then reset. `begin()` performs the same reset. Empty lines remain ignored.
Other control bytes retain their existing parser behavior; no token normalization,
confirmation grammar or SAVE/ACK semantics changed.

Both original findings are reproduced for eligible SAVE with full confirmation,
ACK 2 and RECONCILE ADOPT 1 with CONFIRM_DISCARD: padding to 95 bytes followed by
EXTRA, and a valid command followed by NUL and EXTRA. Whole and fragmented input
are refused without command dispatch, storage writes, marker/slot changes or
calibration changes. The same valid mutating command succeeds after recovery.

The real-router test feeds transport bytes with explicit lengths. Its matrix covers
all fifteen requested cases: within/exact/over limit, long lines, fragmentation,
internal/first/multiple NULs, NUL with overflow, LF recovery, immediate valid next
line, multiple lines in one update, `begin()` reset and CRLF. It runs both with
memory storage and with the real CalibrationPersistenceService, record store and
CalibrationRecordNvsBackend linked to simulated platform APIs. Malformed lines
cause zero `nvs_set_blob`, `nvs_commit` or read-write namespace opens. Positive
controls require three set/commit calls for SAVE and one for ACK or ADOPT, proving
the integrated backend is exercised. The simulator contains no command parser.

### Results and boundaries

- Complete host suite: **44 executables, PASS**, run by `static_audit.py`.
- Actual CommandRouter: **15,044 checks, zero failures**, including the previous
  P3a.1 tests. Persistence service, SAVE gate and P2.4.1 regressions pass unchanged.
- Negative controls: restoring silent overflow truncation or NUL acceptance in
  separate temporary copies of the real router makes the same regressions fail.
  Each must observe unintended memory-storage writes and actual `nvs_set_blob`
  calls; compilation errors or diagnostic-only failures do not count. Both pass
  this detection requirement without failing the pre-existing P3a.1 cases.
- Static audit: **PASS**, 203 source files scanned. Layout suite: **57 tests, PASS**.
- Both clean builds pass with ESP32 core **3.3.11**, pinned 16 MiB/custom partition
  FQBN, PSRAM OPI and explicit **MATDOG_OTA_INGEST_ENABLED=0**. Verification build
  ID: `e82cdab-p3a2-offline`, from the corrected pre-commit working tree. All build
  outputs stay under `/tmp/matdog-p3a2-build-3cvl2sh6`; exported firmware and
  repository manifests were not overwritten.

| Profile | Sketch flash report | Application .bin | Global RAM | RAM left for locals |
|---|---:|---:|---:|---:|
| USB_ONLY | 1,120,319 B | 1,120,464 B | 73,884 B | 253,796 B |
| ROBOT_POWERED | 1,123,455 B | 1,123,600 B | 73,884 B | 253,796 B |

Both generated tables pass `matdog_layout.py check-build`, retaining layout
`MATDOG_16M_2x5M_NVS_V1` and partition-table SHA256
`8f756ecb719c4894b9c23c26bcc171e1d01ae8cda69882950944d5ce264946e7`.
Each app slot remains 5,242,880 B; both images occupy 21.4%. Each ELF contains
14 verified defined symbols for router begin/update/reset/dispatch/PERSIST,
SAVE/ACK/RECONCILE, SAVE gate, Q0 attestation and NVS backend begin/writeMarker.

No changes to marker/A/B protocol, layout, flashing/manifest, OTA, calibrator,
geometry, Q0/transform, motion/gait/stabilization, servo allocation/limits or
movement authorization. RESTORE/P3b remain unimplemented. No device access,
flash, erase, reset, OTA or gait-worktree modification occurred. One corrective
local commit is created; no push, PR or merge.

Residual limits: simulated NVS does not prove physical durability or power-cut
recovery, and offline framing tests do not exercise the live USB driver. Clean
builds retain existing local-credential comment warnings and SCServo warnings
(including ReadMode array bounds); none originates in the framing changes.
These verification artifacts do not authorize a device migration or flash.

## P3a.1 corrective integration — offline verification, 2026-10-02

Initial branch: `feat/calibration-persistence-record-store-v1`; initial HEAD:
`90a2f62b012dc535f479206a2397aef6d1d94f33`. The worktree was clean before this task.
Only the three independent review findings were corrected. No device was accessed.

### Corrections and original reproductions

1. **Current Q0 capture promotion:** `CalibrationQ0CaptureSession` keeps a RAM-only
   attestation of the promoted capture ID and geometry. The explicit Q0 PROMOTE handler
   records it only after preparing the current installation and admitting all 12 transforms.
   The SAVE gate checks that identity as well as the existing geometry, promoted transform
   and per-joint record Q0 checks. A new capture, invalid start, reset or boot clears the
   attestation. The real session and real command path reproduce: first capture promoted;
   second capture with identical ticks; SAVE CHECK refuses `Q0_NOT_PROMOTED`; explicit
   promotion of the second capture permits CHECK. Partial capture/promotion, failed capture,
   stale ID, wrong geometry and a restarted numeric ID after boot also refuse.
2. **Uncertain write block:** the service checks its block before invoking mutating ACK.
   After uncertain SAVE, ACK or RECONCILE, subsequent SAVE/ACK/RECONCILE cannot write.
   The sole exception is a fresh read-only verification of an already acknowledged valid
   generation; it returns ALREADY_ACKNOWLEDGED and leaves the block latched. The original
   A/1 acknowledged, B/2 awaiting, uncertain ADOPT 1, then ACK 2 sequence is tested both
   through the service and actual command handler: write counts, marker bytes and A/1 bytes
   stay unchanged. Lost persisted-ACK reply, duplicate ACK and reboot recovery are covered.
3. **Complete PERSIST token:** dispatch and handler share the same prefix boundary check
   (space or end of line). `PERSISTACK` and `PERSISTSAVE` refuse without a storage write.
   Parser tests compile both actual router translation units and exercise USB framing,
   normalization, dispatch, promotion and the PERSIST handler. Arduino transport and unrelated
   device service methods are fakes; persistence, gates and Q0 implementations are real.

Parser coverage includes STATUS, SAVE CHECK, missing subcommands/generation, negative/zero/
maximum/overflow generations, nonnumeric suffix, extra tokens, misplaced or absent
CONFIRM_DISCARD, maintenance/session/run/executor/capture/diagnostic/authority/permit/operator
and SAFE_OFF gates. SAVE authorization tests begin with writable storage so AWAITING_ACK
cannot mask a missing gate. STATUS/CHECK and malformed commands never write; the transport
counter stays zero. No parser logic is duplicated in the tests.

### Results

- Complete host suite: **44 executables, 436,805 checks, zero failures**.
- Persistence service: **500 checks**; SAVE gate: **604**; actual CommandRouter: **608**.
- P2/P2.4.1 suites pass unchanged, including store fault injection and reboot/ACK regressions.
- Static audit: **PASS**, 201 source files scanned.
- Layout suite: **57 tests, PASS**, using the installed ESP32 core 3.3.11 generator.
- Negative controls use temporary files only: baseline `90a2f62` gate produces **4 failures**,
  baseline service **27 failures**, restoration of the original dispatch/handler prefix
  behavior **64 failures**. The corrected versions of the same suites pass.
- Both clean offline builds pass with ESP32 core **3.3.11**, 16 MiB/custom partition FQBN,
  PSRAM OPI, and explicit **MATDOG_OTA_INGEST_ENABLED=0**. Build directories and outputs are
  under `/tmp`; existing exported firmware/manifests in the repository were not overwritten.
  Verification build ID is `90a2f62-p3a1-offline`, from the corrected pre-commit working tree.

| Profile | Sketch flash report | Application .bin | Global RAM | RAM left for locals |
|---|---:|---:|---:|---:|
| USB_ONLY | 1,120,187 B | 1,120,336 B | 73,876 B | 253,804 B |
| ROBOT_POWERED | 1,123,319 B | 1,123,472 B | 73,876 B | 253,804 B |

Both actual generated tables pass `matdog_layout.py check-build`:
`MATDOG_16M_2x5M_NVS_V1`, SHA256
`8f756ecb719c4894b9c23c26bcc171e1d01ae8cda69882950944d5ce264946e7`.
App slots remain 5,242,880 B each; MATDOG NVS remains at `0xFE0000`, size `0x10000`.
Both images use 21.4% of a slot. The layout tests cover canonical 3072-byte tables and
4096-byte padded regions; no device table was read.

`xtensa-esp32s3-elf-nm -C` finds defined `T` symbols in both ELFs for the NVS backend begin,
service LOAD/SAVE/ACK/RECONCILE, SAVE gate, capture promotion attestation, and router
prefix check/facts/handler. These are linked implementations, not just compiled objects.

### Changed files and boundaries

Production changes are confined to `src/calibration/CalibrationQ0CaptureSession.{h,cpp}`,
`CalibrationSaveGate.{h,cpp}`, `CalibrationPersistenceService.{h,cpp}` and
`src/core/CommandRouter.{h,cpp}`, `CommandRouterPersistence.cpp`.
Tests change `scripts/tests/run_host_tests.sh`, `test_calibration_save_gate.cpp`,
`test_calibration_persistence_service.cpp` and add `calibration_persistence_fixture.h`,
`test_command_router_persistence.cpp`, `router_fake_hardware.cpp` and `router_stubs/`
(Arduino, SPI, SCServo, BNO08x, NeoPixel, ESP OTA/HTTP and FreeRTOS declarations).
Documentation changes are this dated section and `CHANGELOG.md`.

No regression was observed. Marker/A/B protocol, partition table, flashing scripts/manifests,
OTA, motion/gait, JointTransform arithmetic, geometric data, servo allocation and historical
Q0/hardware evidence are unchanged. No P3b/RESTORE, new grant, motion or servo EEPROM write
was introduced. This task creates only one local corrective commit, without push/PR/merge.

Physical NVS durability and real power-cut behavior remain unproven by host storage faults.
Legacy device-layout migration and hardware flash authorization remain separate gates;
these temporary verification artifacts are not hardware release artifacts. Authenticated
image-layout verification for OTA remains pending, and ingest stays disabled. Clean builds
still report pre-existing SCServo warnings (including ReadMode array bounds) and a multiline
comment warning in the local Wi-Fi configuration; none originates in the corrective code.

## Present-day baseline and next gate

> *Annotation 2026-10-08:* this section reflects 2026-10-01. Later status is in the PR-2 and PR-3
> sections at the top of this file and in [`HISTORY_INDEX.md`](../../09_Logs/HISTORY_INDEX.md).

The official Controller baseline is now merged and tagged. The session records below preserve the
state and merge judgements that were true when each session ended; their historical "not merged"
checkboxes are not current project status and are intentionally not rewritten.

| Identity | Value |
|---|---|
| Official release tag | `matdog-controller-v0.1.0` |
| Tagged repository commit | `c54862f38a9cbd5e46d6b1770a6d109cc99b5c02` |
| Exact validated firmware source | `5b371da5482f9b0bd2df1c37ed361250ea54ae8f` |
| Validated application SHA256 | `6e6d92f898dbe95000b53dbb252c7eb5d3deaa9a4b161e2b1934436a76b29364` |

### Latest hardware session — 2026-10-01

| Item | Result |
|---|---|
| Validated firmware source | `dfcecb670d0565d2db1a8152b6cd7ad230bdb87d`; BUILD_ID `dfcecb670d05` |
| Hardware profile | `ROBOT_POWERED`, OTA ingest disabled |
| TRUE Full Calibration | **24/24 hardware PASS**, LF/RF/RH/LH 6/6 each |
| Fine-pass repeatability | <= 4 ticks for every endpoint |
| Final SAFE_OFF | 13/13 verified |
| Persistence | RAM-only; boot restoration not implemented |
| Operational envelopes | Unapproved (`envelope_accepted=0`) |

Evidence: [hardware-validation report](../../09_Logs/Validation_Reports/Full_Calibration_24_Contact_Hardware_2026-10-01/README.md). The merged PR #35 contains the hardware-validated source; the later merge
commit itself was not flashed. This is a development-firmware validation, not a change to the
frozen V0.1 release identity.
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

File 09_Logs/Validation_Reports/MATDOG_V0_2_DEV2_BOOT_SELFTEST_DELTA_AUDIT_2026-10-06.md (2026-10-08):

# MATDOG v0.2.0-dev.2 — Boot Self-Test Delta Audit
Date: 2026-10-06
Base: d7aa369631202aed70458d0c7ff2980534882058 (v0.2.0-dev.1, frozen, preserved)
Branch: fix/matdog-v0.2.0-dev2-boot-selftest
External evidence root:
`~/MATDOG/verification-artifacts/MATDOG_V0_2_DEV2_BOOT_SELFTEST_20261006`

## Hardware finding

v0.2.0-dev.1 booted and ran, but SYSTEM health remained BOOTING because
ROBOT_POWERED requires the servo subsystem while no automatic population
observation occurred (`SERVO detected=UNKNOWN`, `last_census=NOT_RUN`,
dev.1 post-power-cycle runtime log, 2026-10-06T17:38Z).

## Corrected boot contract

ROBOT_POWERED automatically schedules one canonical read-only servo census.
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

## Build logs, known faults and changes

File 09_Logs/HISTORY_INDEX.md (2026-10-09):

# MATDOG history index — June to October 2026

One navigable chronology. It **indexes** existing documents; it adds no new evidence and does not
change any recorded PASS/FAIL result. Where a document or report does not exist on `main`, the row
says so instead of describing it.

> **CHRONOLOGY — NOT CURRENT-STATE AUTHORITY.** Today's state: [root README](../README.md).
> Open blockers: [`OPEN_ITEMS.md`](OPEN_ITEMS.md). Commits and recreated SHAs:
> [`COMMIT_PROVENANCE_MAP.md`](COMMIT_PROVENANCE_MAP.md). Material outside `main`:
> [`EXTERNAL_ARCHIVES.md`](EXTERNAL_ARCHIVES.md).
> Standing limits: `MOTION_AUTHORIZED=0` · `RESTORE=NOT_IMPLEMENTED` · **DO NOT FLASH `main`**.

> **Branch status (2026-10-09).** The 13 historical branches recorded by the consolidation have been deleted
> from GitHub; 9 tags remain. While Draft PR #42 is open the branch `docs/c2-final-sync` also exists; the
> target is `main` alone after it is merged and that branch is deleted. Dated logs and rows below that name a
> branch describe where the content *was*; the original commits are in a non-public archive (owner-reported),
> see [`EXTERNAL_ARCHIVES.md`](EXTERNAL_ARCHIVES.md). Navigable on GitHub: `main` and the tags.

## How to read a row

| Column | Meaning |
|---|---|
| **Status** | One of the project vocabulary terms below, as the cited document records it for its own scope |
| **Documents** | Relative links; all resolve on `main` unless marked |
| **Evidence available** | What a reader can actually open on `main`. "Document only" = a written record without raw artifacts here. "Not on `main`" = referenced but absent |

Status vocabulary: **IMPLEMENTED** (code exists) · **OFFLINE TESTED** · **HARDWARE VALIDATED**
(for the stated scope only) · **ACCEPTANCE BLOCKED** · **DEFERRED** · **SUPERSEDED** · **HISTORICAL**.
A row marked `EXTERNAL_ARCHIVE_PENDING_VERIFICATION` depends on material outside `main` that has not
been verified.

Documentation layers: **CURRENT** = root README, [`ARCHITECTURE.md`](../01_Docs/02_Architecture/ARCHITECTURE.md),
[`ROADMAP.md`](../01_Docs/02_Architecture/ROADMAP.md), Controller
[`DEVELOPMENT_GATES.md`](../05_Firmware/MATDOG_Controller/DEVELOPMENT_GATES.md),
[`VALIDATION.md`](../05_Firmware/MATDOG_Controller/VALIDATION.md),
[`CHANGELOG.md`](../05_Firmware/MATDOG_Controller/CHANGELOG.md). Everything below the dated rows is
**HISTORICAL** unless its status says otherwise.

Per-area indexes: [ADRs](Architecture_Decisions/README.md) · [Development Log](Development_Log/README.md) ·
[Validation Reports](Validation_Reports/README.md) · [ST3215 evidence](ST3215_EVIDENCE_INDEX.md) ·
[Historical archive index](Historical/README.md).

## 1. Architecture stages

| Stage | Dates | Status | Documents | Evidence available |
|---|---|---|---|---|
| Station-mediated control, 12 servos | 2026-06 | **SUPERSEDED** (2026-08-27) | [ADR-001](Architecture_Decisions/ADR-001_Quadruped_Control_Architecture.md), [Project report 2026-06-25](../01_Docs/02_Architecture/Project_Reports/2026-06-25_MATDOG_Project_State_and_Next_Steps.md) | Document only |
| `robot-dog` as MATDOG reference repository | 2026-06-25 | Accepted; the Station bus-control part is **SUPERSEDED** | [ADR-002](Architecture_Decisions/ADR-002_MATDOG_Repository_and_Station_Integration.md) (annotation 2026-10-08) | Document only |
| URDF REV00 canonical kinematic baseline | 2026-06-30 | Accepted; OFFLINE | [ADR-003](Architecture_Decisions/ADR-003_URDF_REV00_Kinematic_Baseline.md), [dev log](Development_Log/2026-06-30_URDF_REV00_Kinematic_Baseline.md), [validation](Validation_Reports/2026-06-30_URDF_REV00_Kinematic_Validation.md) | URDF and meshes in `03_CAD/` |
| Three events: ESP32-S3 replaces Station, 12 servos → 17 allocated slots after the rebuild (13 physically installed today: 12 leg + neck ID 51), hardware decisions frozen | 2026-08-27 | Current architecture | [Historical index](Historical/README.md), [calibration reset](Calibration/MATDOG_CALIBRATION_RESET_2026-08-27.md), [ARCHITECTURE](../01_Docs/02_Architecture/ARCHITECTURE.md) | Documents |
| Third-party reverse-engineering material stays out of `main` | 2026-10-08 | Accepted | [ADR-004](Architecture_Decisions/ADR-004_Third-Party_Reverse_Engineering_Material_Boundary.md) | Manifest by path/SHA-256 only |

## 2. Mechanics, electronics and power

| Phase | Dates | Status | Documents | Evidence available |
|---|---|---|---|---|
| Servo mapping and BOM | not dated here | Reference | [`04_Electronics/`](../04_Electronics/README.md), [`02_BOM/`](../02_BOM/) | Files in those directories |
| 3S power-load analysis | not dated here | Analysis | [`ST3215_Quadruped_3S_Power_Load_Analysis.md`](../01_Docs/01_Analysis/ST3215_Quadruped_3S_Power_Load_Analysis.md) | Document |
| Power, KEY (DALY BMS), charging handoff | 2026-09-19 → 09-20 | HISTORICAL handoff | [2026-09-20 handoff](Development_Log/2026-09-20_MATDOG_POWER_KEY_CHARGING_NEXTGEN_HANDOFF.md), [power states](../04_Electronics/MATDOG_POWER_STATES_AND_CHARGING.md) | Document only (no 2026-09-19 log on `main`) |
| Charging, B-/P- bypass fix, post-rewire power gate A–E, external USB | 2026-09-22 → 09-24 | Post-rewire gate **PASS** (ROADMAP) | [2026-09-24 closeout](Development_Log/2026-09-24_MATDOG_POWER_CHARGING_USB_VALIDATION_CLOSEOUT.md), [`VALIDATION.md`](../05_Firmware/MATDOG_Controller/VALIDATION.md) | Document only |

## 3. Calibration, servo and kinematics (pre-rebuild and Geometry)

| Phase | Dates | Status | Documents | Evidence available |
|---|---|---|---|---|
| Visual zero, static actuation, live FK | 2026-07-02 → 07-07 | **HISTORICAL** (Station, 12 servos; pre-reset) | [dev log](Development_Log/2026-07-06_Visual_Zero_Calibration_and_Static_Control_Checkpoint.md), [validation](Validation_Reports/2026-07-06_Visual_Zero_and_Static_Actuation_Validation.md) | Raw sessions in [`Calibration_Sessions/`](Calibration_Sessions/) |
| C4-A…C4-F offline stand candidate and policies; digital zero; C5-R | 2026-07-08 → 07-10 | OFFLINE / HISTORICAL | [C5-R handoff](Development_Log/2026-07-10_C5R_POST_DIGITAL_ZERO_HANDOFF.md), [C4 reports](Validation_Reports/README.md) | JSON artifacts, [`Calibration/`](Calibration/) |
| Native NormaCore calibrator handoffs (M12 pilot, MIN/MAX) | 2026-07-21 → 07-28 | **HISTORICAL** | [07-21](Development_Log/2026-07-21_NATIVE_NORMACORE_CALIBRATOR_HANDOFF.md), [07-25](Development_Log/2026-07-25_NATIVE_NORMACORE_CALIBRATOR_HANDOFF.md), [07-28](Development_Log/2026-07-28_MATDOG_M12_MIN_MAX_HANDOFF.md) | Records in [`Calibration/`](Calibration/); archive in [`Historical/`](Historical/README.md) |
| LF V25 closeout and repository cleanup | 2026-08-04 | HISTORICAL | [log](Development_Log/2026-08-04_LF_V25_AND_REPOSITORY_CLEANUP.md) | Document |
| Geometry Compiler v1–v5, Phase 2A0 closeout | 2026-08-07 → 08-11 | OFFLINE; per-run status in the artifact index | [log](Development_Log/2026-08-11_PHASE2A0_GEOMETRY_V5_CLOSEOUT.md), [artifact index](Validation_Reports/Geometry_Compiler/README.md) | 85 artifacts on `main`. Pre-squash history of PR #19: tag `archive/2026-08-11/pr19-geometry-v5-pre-squash`, `EXTERNAL_ARCHIVE_PENDING_VERIFICATION` |
| ST3215 bench QC (26/26 runs) and provisioning (17/17 units) | 2026-08-24 → 08-27 | Historical bench evidence, **HARDWARE VALIDATED** for the bench scope only; 17/17 provisioning does **not** mean 17 servos are installed (13 are installed today: 12 leg + neck ID 51; 17 are the allocated slots) | [QC](Validation_Reports/ST3215_Bench_QC_2026-08-24/README.md), [provisioning](Validation_Reports/ST3215_Provisioning_2026-08-27/README.md), [handoff](Development_Log/2026-08-27_ST3215_CANONICAL_ARCHIVE_HANDOFF.md), [index](ST3215_EVIDENCE_INDEX.md) | Artifacts and checksums on `main` |
| Calibration reset after reassembly | 2026-08-27 | Current rule: all calibration redone from zero | [reset notice](Calibration/MATDOG_CALIBRATION_RESET_2026-08-27.md) | Document |
| Calibrator V1 H0 | 2026-08-28/29 | HISTORICAL | PR #22 (closed); tag `archive/2026-08-29/full-leg-calibrator-v1-h0` | `EXTERNAL_ARCHIVE_PENDING_VERIFICATION` |

## 4. Controller software and first hardware

| Phase | Dates | Status | Documents | Evidence available |
|---|---|---|---|---|
| Controller V0.1 (USB_ONLY), Sessions 1, 2, 2.1, 2.2 | 2026-09-15 | **HARDWARE VALIDATED** (USB_ONLY scope), tag `matdog-controller-v0.1.0` | [`VALIDATION.md`](../05_Firmware/MATDOG_Controller/VALIDATION.md) | Tagged commit on `main`. No dated log |
| ROBOT_POWERED preparation; G3 / G3.1 no-motion | 2026-09-17 → 09-18 | **G3 PASS (formal)**, G3.1 PASS | [G3 plan](../05_Firmware/MATDOG_Controller/G3_ROBOT_POWERED_VALIDATION_PLAN.md), [ROADMAP](../01_Docs/02_Architecture/ROADMAP.md) | Recorded in ROADMAP and `VALIDATION.md`; no dated log on `main` |
| NextGen integration I1–I9 (LED, source signature, actuator runtime, HostLink, Wi-Fi/OTA and Web decisions, freeze) | 2026-09-25 | IMPLEMENTED / OFFLINE TESTED | [Development Log index, 2026-09-25/26 group](Development_Log/README.md) | Logs |
| F0 final flash readiness gates, candidate V3 first flash | 2026-09-25 → 09-26 | Candidate hardware-validated for its scope, tag `matdog-controller-nextgen-hw-validated-v1` | [F0](Development_Log/2026-09-25_F0_FINAL_FLASH_READINESS.md), [V3 flash](Development_Log/2026-09-26_HARDWARE_VALIDATION_CANDIDATE_V3.md) | Logs; tagged commit |
| LED Status Manager V2 | 2026-09-26 | **HARDWARE VALIDATED** (focused), tag `matdog-led-v2-focused-hw-validated-v1` | [final](Development_Log/2026-09-26_LED_STATUS_MANAGER_V2_FINAL.md), [HW validation](Development_Log/2026-09-26_LED_STATUS_MANAGER_V2_HW_VALIDATION.md) | Logs; tagged commit |
| Calibration readiness CR0–CR3; CR2-C current-installation q0 | 2026-09-27 → 09-28 | CR2-C read-only capture **PASS**; CR3 offline | [CR0/CR1](Development_Log/2026-09-27_CALIBRATION_READINESS_CR0_CR1.md), [CR2-C session](Development_Log/2026-09-27_CR2C_Q0_HARDWARE_SESSION.md), [CR2-C evidence](Validation_Reports/Calibration_Q0_CR2C_2026-09-27/README.md), [CR3 logs](Development_Log/README.md) | Evidence package with checksums |

## 5. Calibration on hardware, persistence, recovery and thermal

| Phase | Dates | Status | Documents | Evidence available |
|---|---|---|---|---|
| Full Calibration generalized to four legs; 24-contact sequence geometry | 2026-09-29 → 09-30 | IMPLEMENTED / OFFLINE | [four-leg](Development_Log/2026-09-29_CALIBRATION_FULL_4LEG.md), [24-contact](Development_Log/2026-09-30_TRUE_24_CONTACT_FULL_CALIBRATION.md), [sequence geometry](Validation_Reports/Full_Calibration_Sequence_Geometry_2026-09-30/README.md) | Geometry artifacts |
| TRUE Full Calibration 24/24 | 2026-10-01 | **HARDWARE VALIDATED** for that session (`all_contact_calibrated=1`); RAM-only at the time; no envelope approved | [report](Validation_Reports/Full_Calibration_24_Contact_Hardware_2026-10-01/README.md), [status sync](Development_Log/2026-10-01_PROJECT_STATUS_DOCUMENTATION_SYNC.md) | Report, checksums, tables. PR #35, #36 |
| Flash layout M0 (offline), M0.1–M0.2 | 2026-10-02 | OFFLINE | [M0](Development_Log/2026-10-02_M0_FLASH_LAYOUT_OFFLINE.md), [M0.1](Development_Log/2026-10-02_M0_1_MIGRATION_WRITE_HARDENING.md), [M0.2](Development_Log/2026-10-02_M0_2_HARDWARE_ALIGNMENT.md), [runbook](../05_Firmware/MATDOG_Controller/FLASH_LAYOUT_M0_RUNBOOK.md) | Logs |
| M0.4 P1 closed; encrypted flash backup | 2026-10-03 | P1 closed; backup verified per the log | [P1](Development_Log/2026-10-03_M0_4_P1_CLOSED.md), [checkpoint](Development_Log/2026-10-03_M0_4_P1_CHECKPOINT.json), [`09_Backups/ESP32/`](../09_Backups/ESP32/README.md) | Manifest and receipt on `main`; encrypted archive is a GitHub Release asset |
| M0.4 P2 (layout migration) | 2026-10-03 | Prepared (log states "not executed" at its date). Execution report **not on `main`** | [P2 prepared](Development_Log/2026-10-03_M0_4_P2_PREPARED.md), [ROBOT_POWERED enablement](Development_Log/2026-10-03_M0_4_ROBOT_POWERED_ENABLEMENT.md) | `EXTERNAL_ARCHIVE_PENDING_VERIFICATION` for the execution record |
| Post-ABORT recovery and thermal telemetry (offline) | 2026-10-03 | OFFLINE TESTED | [log](Development_Log/2026-10-03_POST_ABORT_THERMAL_OFFLINE_RELEASE.md), [runbook](../05_Firmware/MATDOG_Controller/POST_ABORT_RECOVERY_RUNBOOK.md) | Log |
| Calibration Persistence V1 (A/B NVS record, SAVE/ACK/RECONCILE, boot LOAD) | 2026-10-02 → 10-06 | **IMPLEMENTED** on `main`; SAVE/ACK and LOAD across a reset observed on the dev.3 candidate; no real power cycle; `RESTORE` NOT_IMPLEMENTED; hardware acceptance **ACCEPTANCE BLOCKED** | [PR-1 log](Development_Log/2026-10-08_PR1_PERSISTENCE_LAYOUT_V1_INTEGRATION.md), [dev.3 audit](Validation_Reports/MATDOG_V0_2_DEV3_THERMAL_DELTA_AUDIT_2026-10-06.md) | Code on `main`; audit document |

## 6. Wi-Fi, OTA and convergence lines

| Phase | Dates | Status | Documents | Evidence available |
|---|---|---|---|---|
| Wi-Fi / provisioning / OTA V1 → V3 | 2026-10-04 | IMPLEMENTED / OFFLINE TESTED; **not hardware tested**; no release | [V1 log](Development_Log/2026-10-04_WIFI_OTA_SHELLY_V1.md), [V3 offline](Validation_Reports/2026-10-04_WIFI_OTA_SHELLY_V3_OFFLINE.md), [runbook](../05_Firmware/MATDOG_Controller/WIFI_OTA_SHELLY_HARDWARE_RUNBOOK.md) | Documents; code on `main` since PR #39 |
| dev.1 convergence | 2026-10-05 | HISTORICAL record of the integration branch | [`Convergence/MATDOG_V0_2_DEV1.md`](../01_Docs/02_Architecture/Convergence/MATDOG_V0_2_DEV1.md) (quotes operator-machine paths) | Document. Branch `integration/matdog-controller-v0.2.0` deleted; original commits in the non-public archive (owner-reported) |
| Motion library G1 → G5-A (pure, host-tested, unwired) | G3 log dated 2026-09-28; other dates not established from `main` | Library **IMPLEMENTED**; execution suites and evidence **DEFERRED** (ADR-004); never hardware-authorized | [`src/motion/README.md`](../05_Firmware/MATDOG_Controller/src/motion/README.md), [CONTACT_STAND](../05_Firmware/MATDOG_Controller/src/motion/CONTACT_STAND.md), [STARTUP_TIMING](../05_Firmware/MATDOG_Controller/src/motion/STARTUP_TIMING.md), [STABILIZATION](../05_Firmware/MATDOG_Controller/src/motion/STABILIZATION.md), [PR-2 manifest](../05_Firmware/MATDOG_Controller/scripts/tests/motion_integration_manifest_pr2.json) | Sources and design notes on `main`. G3 report and G4/G4.1/G5-A/G35 evidence: **not on `main`**; their branch is deleted and they remain only in the non-public archive (owner-reported). Not republished (ADR-004) |
| dev.2 boot census; hardware 13/13; calibration stopped at LF (block-read temperature artifact) | 2026-10-06 | dev.2 code on `main`; hardware result of the candidate | [log](Development_Log/2026-10-06_BOOT_SELFTEST_CENSUS_CORRECTION.md), [dev.2 audit](Validation_Reports/MATDOG_V0_2_DEV2_BOOT_SELFTEST_DELTA_AUDIT_2026-10-06.md) | Audit document; raw evidence root is on the operator machine (`EXTERNAL_ARCHIVE_PENDING_VERIFICATION`) |
| dev.3 thermal verdict from direct reads; 24/24; SAVE/ACK and LOAD across a reset; automatic recovery not triggered | 2026-10-06 | dev.3 code on `main`; candidate **not an accepted release** | [log](Development_Log/2026-10-06_THERMAL_DIRECT_VERDICT_DEV3.md), [dev.3 audit](Validation_Reports/MATDOG_V0_2_DEV3_THERMAL_DELTA_AUDIT_2026-10-06.md) | Audit document; raw evidence external |
| **Hardware Validation 2026-10-07 (dev.3)** | 2026-10-07 | Execution **COMPLETE**, acceptance **BLOCKED** (owner statement) | Referenced from the [root README](../README.md); no report on `main` | **Not on `main`**; not reconstructed. `EXTERNAL_ARCHIVE_PENDING_VERIFICATION` |

## 7. Repository convergence, PR #37 – #41 (2026-10-08 – 2026-10-09)

#37 is a safety notice (documentation); #38–#40 integrate **source** into `main`; #41 is the C1 documentation
consolidation. None is a release, a flash authorization or a hardware acceptance. Merge and recreated SHAs: [`COMMIT_PROVENANCE_MAP.md`](COMMIT_PROVENANCE_MAP.md).

| PR | Subject | Log |
|---|---|---|
| #37 | Flash layout safety notice (docs only) | [divergence notice](Development_Log/2026-10-08_FLASH_LAYOUT_DIVERGENCE_NOTICE.md), [safety notice](../05_Firmware/MATDOG_Controller/FLASH_LAYOUT_SAFETY_NOTICE.md) |
| #38 | Persistence V1 and flash layout V1 (13 original SHAs preserved) | [PR-1](Development_Log/2026-10-08_PR1_PERSISTENCE_LAYOUT_V1_INTEGRATION.md) |
| #39 | Selective dev.1 integration; XGO extracts excluded | [PR-2](Development_Log/2026-10-08_PR2_SELECTIVE_DEV1_INTEGRATION.md), [ADR-004](Architecture_Decisions/ADR-004_Third-Party_Reverse_Engineering_Material_Boundary.md) |
| #40 | Selective dev.2/dev.3 source delta (7 commits recreated) | [PR-3](Development_Log/2026-10-08_PR3_DEV2_DEV3_SELECTIVE_INTEGRATION.md) |
| #41 | C1 documentation and history consolidation (Markdown only) | this index, [`OPEN_ITEMS.md`](OPEN_ITEMS.md), [`COMMIT_PROVENANCE_MAP.md`](COMMIT_PROVENANCE_MAP.md) |

## 8. Pull requests before #37, by period

Titles are paraphrased from the GitHub PR list (#15 is not described here); the repository documents above are the evidence.

| Period | PRs | Theme |
|---|---|---|
| before 2026-08-04 (dates not recorded here) | #1 | Repository foundation |
| before 2026-08-04 (dates not recorded here) | #2, #3, #5–#9 | Experiments, **ARCHIVED** |
| before 2026-08-04 (dates not recorded here) | #4 | Milestone I documentation |
| 2026-08-04 | #10–#12 | LF V25 closeout and cleanup |
| 2026-08-07 → 08-11 | #13, #14, #16–#19 | Canonical geometry-first architecture; Geometry Compiler phases to V5 |
| date not recorded here | #20 | Phase 2A0 close |
| 2026-08-27 → 08-28 | #21, #22 | ST3215 canonical archive; Calibrator V1 (closed) |
| 2026-09-05 | #23 | BNO085 viewer |
| 2026-09-15 → 09-24 | #24, #25, #26, #27 | Controller V0.1; alignment; ROBOT_POWERED; DALY KEY and power architecture |
| 2026-09-26 | #28, #29 | NextGen integration; LED V2 |
| 2026-09-27 → 09-29 | #30, #31, #32, #33 | CR0–CR2C; CR3 motion enablement; four-leg Full Calibration; current q0 |
| 2026-09-30 → 10-01 | #34 (closed), #35, #36 | Staged search (closed); TRUE 24-contact; status sync |

## 9. References that depend on material outside `main`

| Reference | Where | Class | Handling |
|---|---|---|---|
| G3 report permalink to commit `e170471…` | [`STARTUP_TIMING.md`](../05_Firmware/MATDOG_Controller/src/motion/STARTUP_TIMING.md) line 162; [PR-2 log](Development_Log/2026-10-08_PR2_SELECTIVE_DEV1_INTEGRATION.md) | **Archive-dependent, HISTORICAL.** The commit is not an ancestor of `main`; its only branch has been deleted, so the link should be treated as unavailable. The PR-2 log calls it "immutable": that holds for the commit, not for the availability of the link | `STARTUP_TIMING.md` is SHA-256-pinned in the PR-2 manifest and is left unchanged. Provenance in [`COMMIT_PROVENANCE_MAP.md`](COMMIT_PROVENANCE_MAP.md); recovery through the archive only ([`EXTERNAL_ARCHIVES.md`](EXTERNAL_ARCHIVES.md) §6) |
| Convergence audit report | [`FLASH_LAYOUT_SAFETY_NOTICE.md`](../05_Firmware/MATDOG_Controller/FLASH_LAYOUT_SAFETY_NOTICE.md) Sources | Archive-dependent | Link replaced by provenance text; the audit branch is deleted and the report is in the non-public archive (owner-reported) |
| dev.3 delta audit | three documents | Equivalent file is on `main` (blob-identical to the one at `b764c25`) | Relative links |
| Installed-firmware provenance commit `b3fd945` | several documents | Not an ancestor of `main` | SHA kept as text; recreated as `e028dd8` |
| Operator-machine paths in older logs and in the dev.1 convergence note | various | HISTORICAL, not resolvable from the repository | Left as recorded |

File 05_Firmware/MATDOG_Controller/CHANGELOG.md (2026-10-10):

# MATDOG Controller — Changelog

> **How to read (added 2026-10-08).** "Unreleased" means not part of an accepted release. The PR-1,
> PR-2 and PR-3 entries are integrated **in source** on `main`; none is a release approval. dev.3 is
> a candidate: Hardware Validation 2026-10-07 has execution COMPLETE and acceptance BLOCKED. A build
> of `main` is not shown to be byte-identical to the installed firmware. **DO NOT FLASH MAIN.**
> Entries are newest-integration first, then in the order they were written. The dated sequence and
> the original-to-recreated SHA map are in [`HISTORY_INDEX.md`](../../09_Logs/HISTORY_INDEX.md) and
> [`COMMIT_PROVENANCE_MAP.md`](../../09_Logs/COMMIT_PROVENANCE_MAP.md).

## Unreleased — LED RMT DMA + dirty-frame selective source integration — 2026-10-10

- **Source:** only `src/status/LedRing.cpp` and `LedRing.h` were copied byte-for-byte from the physically validated local LED candidate `fee9383156fa`. No historical dev.3 ancestry, third-party XGO material, AP implementation, actuator logic or private backups were imported.
- **Transport:** ESP32-S3 RMT DMA for 12 WS2812B GRB LEDs (GPIO47); diagnostic `LED_TRANSPORT=RMT_DMA`, explicit fallback to the prior transport if DMA fails. Fixed-frame writes occur on change or a 250 ms refresh. `USB_ONLY` continues to withhold power-rail-driven output.
- **Hardware evidence:** application-only flash/read-back PASS, DMA active, servo census 13/13, READY, SoftAP active without clients, ten minutes of no visually observed LED anomalies, servo timing consistent with dev.3. [Limited validation report](../../09_Logs/Validation_Reports/MATDOG_LED_RMT_DMA_DIRTY_FRAME_HW_VALIDATION_2026-10-10.md).
- **Scope boundary:** hardware validation is of the **installed `fee9383` image**, not of a new `main` build. The dev.3 overall acceptance remains BLOCKED; `MOTION_AUTHORIZED=0`, `RESTORE=NOT_IMPLEMENTED`. The AP HTTP 403 work is separate. **DO NOT FLASH MAIN.**

## Unreleased — PR-3: dev.2/dev.3 source delta on `main` (0.2.0-dev.3) — 2026-10-08

- **What `main` gains.** Seven commits recreated from the dev.2/dev.3 candidate (`bac652f`,
  `d0ede36`, `d67eaa1`, `62812cd`, `2f23247`, `b3fd945`, `b764c25`); each message carries the full
  `Original-SHA:`. They are recreated, not merged: the originals descend from `3f23439`, which holds
  third-party decompiler material that must not enter the history of `main` (ADR-004). The originals
  are not ancestors of `main`. They were preserved on `backup/matdog-dev3-preservation-20261008`, a branch deleted on GitHub by 2026-10-09; the originals are in a non-public archive (owner-reported, see [`EXTERNAL_ARCHIVES.md`](../../09_Logs/EXTERNAL_ARCHIVES.md)).
- **Source.** The dev.2 read-only boot servo census (ROBOT_POWERED), the dev.3 thermal verdict from
  direct reads only, the host runner's one-shot post-abort recovery, and the identity
  `0.2.0-dev.3`. Every recreated file is byte-identical to its original; `CHANGELOG.md` differs
  only in position of the added entries.
- **Records.** The dev.2/dev.3 development logs and delta audits are historical records of the
  candidate on the robot; they are not results for a `main` build.
- **Unchanged contracts.** `MOTION_AUTHORIZED=0`, `RESTORE=NOT_IMPLEMENTED`, OTA ingest default 0,
  layout `MATDOG_16M_2x5M_NVS_V1`, no actuator path from `src/motion`. No pre-existing anomaly was
  corrected.
- **Not accepted.** dev.3 Hardware Validation 2026-10-07: execution COMPLETE, acceptance BLOCKED. No
  release is approved. **Do not flash `main`**; see
  [`FLASH_LAYOUT_SAFETY_NOTICE.md`](FLASH_LAYOUT_SAFETY_NOTICE.md) and the
  [PR-3 log](../../09_Logs/Development_Log/2026-10-08_PR3_DEV2_DEV3_SELECTIVE_INTEGRATION.md).

## 0.2.0-dev.3 — thermal verdict from direct reads; automatic post-abort recovery — 2026-10-06

- The PresentTemperature byte of the 15-byte feedback block read is diagnostic only. On
  the robot it intermittently reads 71..150 on the servo that is moving while a direct
  read 50 ms later says ~32 C (23 such samples in the 2026-10-01 24/24 run, 19 on
  2026-10-03, 4 in 38 s on 2026-10-06). Above the limit it only opens a confirmation.
- The thermal verdict is taken from DIRECT single-register reads alone: three direct
  samples over the unchanged 70 C limit are `CONFIRMED`; three at or under it refute the
  block read (`BULK_TEMP_ARTIFACT_SUSPECT`, counted, logged, never latched); a failed,
  invalid, incoherent or expired confirmation is `THERMAL_TELEMETRY_FAULT`. Both abort
  verdicts publish a value over the limit, so the run ends in SAFE_OFF as before.
- Removed: the per-servo latch (three refuted samples in 30 s, eight per boot) that
  stopped LF at UPPER MAX on 2026-10-06 with every servo at 32..35 C. Every confirmation
  sequence that aborted before still aborts; no limit, current, contact, torque, speed or
  geometry parameter changed.
- `calibration_hw_session.py`: after a failed leg (SAFE_OFF 13/13 and export done) the
  runner starts the firmware's own witnessed `POST_ABORT RECOVERY` once, only for an
  allow-listed search verdict in an UPPER/LOWER probe phase and only with fresh proof of
  the promoted q0, geometry, census, preflight, direct temperatures and torque-off. Thermal
  verdicts, current, communication, readback, status and operator aborts never recover.
  `--no-auto-recovery` disables it. The BMS stream is switched off after a failed phase.
- No recovery across a reboot exists: see the
  [dev.3 delta audit](../../09_Logs/Validation_Reports/MATDOG_V0_2_DEV3_THERMAL_DELTA_AUDIT_2026-10-06.md).

## 0.2.0-dev.2 — ROBOT_POWERED boot self-test census — 2026-10-06

- ROBOT_POWERED arms exactly one canonical read-only servo census (11..55, 13 expected,
  52..55 absent by design) in `Controller::begin()`. It advances from `update()` at one
  Ping per tick: no torque, GoalPosition, EEPROM or SAFE_OFF write. USB_ONLY is unchanged.
- Servo subsystem health under ROBOT_POWERED is the completed census verdict: pending is
  BOOTING, PASS is OK, any other verdict or a census that cannot be armed is FAULT. A later
  operator census replaces it on completion; the previous verdict is kept while it runs.
- Boot banner: `startup_servo_census : ENABLED_READ_ONLY_INCREMENTAL` replaces
  `startup_servo_scan : DISABLED`, plus `STARTUP_SERVO_CENSUS=RUNNING|PASS|FAIL|START_FAILED`.
  Older entries and plans quoting the previous line describe earlier builds.
- Static audit owns the new wiring (`check_startup_servo_selftest_wiring`, three rejected
  mutations); `ServoBus::begin()` still may not ping. Stale `0.2.0-dev.1` test
  expectations updated. No motion, calibration, persistence, OTA or layout change.
- MOTION_AUTHORIZED stays 0, RESTORE stays NOT_IMPLEMENTED. See the
  [delta audit](../../09_Logs/Validation_Reports/MATDOG_V0_2_DEV2_BOOT_SELFTEST_DELTA_AUDIT_2026-10-06.md).

## Unreleased — PR-2: selective dev.1 integration (0.2.0-dev.1) — 2026-10-08

- **Merged with original SHAs.** `13da04a` and its 12 ancestors from
  `integration/matdog-controller-v0.2.0` (`125d981`…`13da04a`) enter `main` by a merge commit.
  This brings: post-abort recovery and thermal acquisition, guarded release stages with native
  DALY supervision, startup RF recovery, Wi-Fi provisioning and gated TLS OTA V3, charging
  presentation priority, and the pure motion library G1 to G5-A (`src/motion`, unwired).
- **Recreated as new commits** (the originals descend from `3f23439`, which holds third-party
  decompiler material that must not enter the history of `main`; each message carries the
  original SHA, and the originals are not ancestors of `main`):
  - `1cec973`: dev.1 identity (`kFirmwareVersion = "0.2.0-dev.1"`), build provenance, isolated
    offline build artifacts. Byte-identical.
  - `53aa962`: safety-gate extension. Five files byte-identical. `run_host_tests.sh` states that
    the motion execution suites are DEFERRED. `run_motion_convergence_tests.py` keeps the source,
    purity, dependency and wiring checks, reads the new manifest
    `motion_integration_manifest_pr2.json` and fails if a deferred artifact is present.
  - `d7aa369`: persistence schema exposed through the owner boundary. Byte-identical.
- **Deferred, not integrated:** 286 artifacts (listed by path and SHA-256 in the manifest): the
  motion host tests and fresh oracles, the audit tooling, the G35/G4/G4.1/G5-A evidence, and 47
  XGO-named files including 38 third-party decompiler extracts. No test or check was removed.
- **Unchanged contracts:** `MOTION_AUTHORIZED=0`, `RESTORE=NOT_IMPLEMENTED`, OTA ingest default 0,
  no actuator path from `src/motion`.
- **Do not flash `main`** on the current robot; see
  [`FLASH_LAYOUT_SAFETY_NOTICE.md`](FLASH_LAYOUT_SAFETY_NOTICE.md) and the
  [PR-2 log](../../09_Logs/Development_Log/2026-10-08_PR2_SELECTIVE_DEV1_INTEGRATION.md).

## Unreleased — PR-1: Calibration Persistence V1 and flash layout V1 on `main` — 2026-10-08

- **What merges.** `feat/calibration-persistence-record-store-v1` at `7b258b3` merges into `main`
  with a merge commit; the 13 original commits keep their SHAs.
- **What `main` gains.** This is a code integration, not a documentation-only change. `main`
  gains the firmware sources, scripts, tests and partition table (`partitions.csv`, layout
  `MATDOG_16M_2x5M_NVS_V1`) developed on the Persistence V1 line.
- **What is not altered.** None of these files differs from `7b258b3`: the merge and the PR-1
  documentation commits change no source, script, test or partition file.
- **Already described below.** The P2.3 (flash layout V1), P2.4, P2.4.1, P3a, P3a.1 and P3a.2
  entries, previously unreleased on a branch, are now on `main`.
- **Commits not described below.** These add M0 migration tooling and records (offline only):
  - `ebb6078`: M0 runbook, `migration_m0.py`, offline checks;
  - `174aa04`: pinned esptool 5.3.1 writer with retries disabled;
  - `2757604`: hardware alignment, unproven recovery blocked;
  - `b19a98e`: ROBOT_POWERED migration qualification;
  - `7b258b3`: P1 close with the encrypted backup record.
- **What is unchanged.** Firmware version literal still `0.1.0`. `MOTION_AUTHORIZED=0`, `RESTORE`
  not implemented, no hardware acceptance of a `main` build.
- **Do not flash `main`** on the current robot; see
  [`FLASH_LAYOUT_SAFETY_NOTICE.md`](FLASH_LAYOUT_SAFETY_NOTICE.md).

## Unreleased — Wi-Fi / provisioning / TLS OTA V3 (isolated, offline) — 2026-10-04

- Add a core-0 radio/config worker, dual STA profiles, protected recovery AP, bounded
  asynchronous scans/optional roaming and conservative HWCDC modem-sleep fallback OFF.
- Add offline six-tab portal, physical USB admin/AP key provisioning, AP-only writes,
  peer-bound sessions/CSRF and ACTIVE/PENDING standard-NVS trials with readback/CRC.
- Require STA TLS before the existing OTA nonce/HMAC writer; add a CA/SAN/pinned
  uploader and correlate cross-task mailbox delivery atomically. No implicit reboot.
- Reserve configuration quiet windows against calibration/persistence and RUN entry.
  Calibration record algorithms, partition layout and defaults USB_ONLY/ingest 0 remain.
- Add fault, mutation, real-adapter/fake-radio, TLS loopback and DOM tests; align inherited
  stale audit pins and fixture linkage to the unchanged 1a5e008 calibration integration.
- Provisional base; no hardware access or main merge. Remote reboot BLOCKED;
  hardware persistence acceptance, RF timing, TLS resources and OTA/rollback TO_TEST.

## Unreleased — post-ABORT recovery and thermal acquisition (offline) — 2026-10-03

- Add explicit current-boot recovery for witnessed UPPER/LOWER probe interruptions,
  restoring geometric dependencies before serial Q0 recovery and verified SAFE_OFF.
  Retain the ordinary 64-tick gate, all protections, Q0 and completed leg records.
- Validate servo read packet ID/width/status/checksum and bound the whole UART response.
  Confirm only hot samples adaptively (up to five, three hot), without sleeps or
  new commands while pending. Invalid reads and repeated anomalies fail closed.
- Extend the existing runner with post-abort/resume and SAVE/ACK/post-reboot verification.
  Require explicit RAM evidence discard before replacing an acquisition.
- No hardware access, EEPROM writes, partition/NVS erasure, gait changes or boot motion.
  See [release report](../../09_Logs/Development_Log/2026-10-03_POST_ABORT_THERMAL_OFFLINE_RELEASE.md)
  and [workflow](POST_ABORT_RECOVERY_RUNBOOK.md).

## Unreleased — P3a.2 USB command framing hardening (offline, no hardware) — 2026-10-02

- CommandRouter latches overflow or NUL for the entire USB line and discards it
  through LF, across `update()` calls. No prefix is dispatched. LF and `begin()`
  clear the buffer, length and error; subsequent lines are received normally.
- The buffer stays 96 bytes: 95 payload bytes are accepted, the 96th invalidates
  the line. CR remains ignored, preserving LF/CRLF behavior and command grammar.
  Invalid lines report `ERROR=COMMAND_LINE_OVERFLOW` or `ERROR=COMMAND_LINE_NUL`
  at LF; the first error is retained.
- Real-router raw-byte regressions cover both findings for SAVE, ACK and
  RECONCILE ADOPT, including fragmented input, recovery and `begin()` reset.
  An integrated real NVS adapter test observes `nvs_set_blob`/`nvs_commit`:
  rejected lines make zero calls and leave marker, slots and calibration unchanged.
  Temporary-source mutation tests independently restore each defect and must
  detect writes through both storage paths. Existing P2.4.1/P3a.1 tests remain.

## Unreleased — P3a.1 corrective persistence integration (offline, no hardware) — 2026-10-02

- SAVE now requires a RAM attestation of the exact current `capture_session_id`,
  recorded only after explicit current-installation Q0 promotion admits all twelve
  transforms. New capture, failed start, reset and boot clear it. Historical transforms
  with identical ticks cannot attest a new capture. Existing geometry and per-joint
  record/transform comparisons still apply; Q0 values and kinematics are unchanged.
- The service refuses every mutating SAVE/ACK/RECONCILE after an uncertain outcome.
  A repeated ACK may only verify an already acknowledged, valid generation by a fresh
  read-only scan; it never writes or clears the block. The marker/A/B protocol is unchanged.
- PERSIST dispatch and handler require a complete token (space or end of line).
  `PERSISTACK` and `PERSISTSAVE` cannot reach a storage operation.
- Host coverage now compiles both real CommandRouter translation units, exercising
  USB framing, dispatch, the explicit Q0 promotion command and the persistence handler.
  Only platform transport and unrelated hardware methods are simulated. Tests check
  malformed arguments, generation bounds, authorization gates, read-only commands,
  identical recapture and uncertain reconciliation with storage write counts/bytes.

## Unreleased — P3a Controller integration of Calibration Persistence V1 (offline, no hardware) — 2026-10-02

Wires the P2–P2.4.1 persistence into the Controller. It adds diagnostics and two explicit,
operator-driven persistent actions (SAVE, ACK) plus a controlled reconciliation. It restores
nothing and authorizes no movement: every reply states `MOTION_AUTHORIZED=0` and STATUS prints
`RESTORE=NOT_IMPLEMENTED`. **Do not load this firmware on a device that still has the legacy
`app3M_fat9M_16MB` partition table**: there is no `matdog_nvs` partition, the boot LOAD reports
`NVS_UNAVAILABLE` (PARTITION_MISSING) and SAVE/ACK/RECONCILE are refused. Nothing is formatted.

- **Boot:** in `Controller::begin()`, right after `geometry_profile_.bind()` and before any
  actuator/servo/service/command init: `persistence_backend_.begin()`, then a read-only LOAD.
  No servo bus traffic. The result is kept for diagnostics only. `CalibrationPersistenceService`
  (pure) owns the single `CalibrationRecordStore`; the Controller owns the service (no stack copy).
- **`@CALIBRATION PERSIST STATUS`** (read-only): NVS state, marker, acknowledged/awaiting generation,
  slots A/B, boot and last LOAD verdict, write block, error codes, whether a valid persistent
  calibration is available (information, not an authorization).
- **`@CALIBRATION PERSIST SAVE CHECK` / `SAVE CONFIRM_SAVE_FULL_CALIBRATION`**: `CalibrationSaveGate`
  proves, in a fixed order, persistence ready, no write in doubt, saveable storage state,
  maintenance, no live session / armed run / executor / Q0 capture / servo diagnostic, authority
  NONE, permit revoked, no operator authorization, SAFE_OFF evidence, 24/24 Full Calibration,
  closed leg runs, current geometry, complete and PROMOTED fresh Q0, record buildable/valid/accepted
  and record q0 == promoted q0 per joint. A fact that cannot be proven refuses and is named.
  Success reports the generation and `ACK_REQUIRED=1 SAVE_CONCLUDED=0`.
- **`@CALIBRATION PERSIST ACK <generation>`**: store `acknowledge()`; OK / ALREADY_ACKNOWLEDGED /
  WRONG_GENERATION / INVALID_RECORD / UNCERTAIN.
- **`@CALIBRATION PERSIST RECONCILE ADOPT <generation> [CONFIRM_DISCARD]` /
  `RECONCILE DECLARE_NOTHING [CONFIRM_DISCARD]`**: maintenance only, no actuator activity, fresh
  LOAD, `planReconciliation`, marker written and read back, state re-classified. DECLARE is refused
  while the acknowledged record is intact; anything that drops a valid generation needs
  `CONFIRM_DISCARD`. No automatic deletion; slots are never erased.
- An uncertain SAVE/ACK/RECONCILE outcome blocks further persistent writes until the next boot.
- Tests: `test_calibration_persistence_service`, `test_calibration_save_gate`; static audit
  `check_calibration_persistence_integration`.

## Unreleased — P2.4.1 Durable acknowledgment and generation protection (offline, no hardware) — 2026-10-02

Fixes the blocker found by the independent review of P2.3/P2.4: "verified on flash" was treated as
"confirmed", so a SAVE that published its last marker but never delivered `SAVE=OK` made the next
boot serve that generation as confirmed; a later failed SAVE could then overwrite the generation
the caller had actually acknowledged. Persistence layer only; still **not integrated** into the
Controller (no command, no boot hook).

- **Marker schema 2** (same 28 bytes, same key `M`): `acknowledged_generation` (last generation the
  CALLER acknowledged; its slot is protected), `begun_generation`, state `IDLE` (nothing in flight),
  `PENDING` (SAVE in flight / interrupted), `AWAITING_ACK` (record written and read back, caller has
  not acknowledged). Schema 1 (never installed) and unknown schemas are MARKER_INCOMPATIBLE: this
  build neither interprets nor overwrites them.
- **SAVE** keeps acknowledged G, registers G+1 PENDING, writes + reads back the free slot, registers
  `AWAITING_ACK`, returns `SAVE=OK generation=G+1`. `SaveStatus::OK` now means "verified, awaiting
  ACK"; the record is not served and the previous slot is NOT reusable. No new SAVE is accepted
  while a generation awaits its ACK (`ACKNOWLEDGMENT_REQUIRED`, zero mutations).
- **ACK** (`CalibrationRecordStore::acknowledge(g, profile)`, pure; planned by
  `planAcknowledgment`): rescans, requires class AWAITING_ACK and `g` == the awaiting generation,
  writes and reads back `IDLE(g, g)`. Only then does G+1 replace G. Duplicate ACK of the
  acknowledged generation is idempotent (`ALREADY_ACKNOWLEDGED`, no write); other generations,
  incomplete/incompatible records, lost acknowledged generation or damaged marker are refused with
  no mutation. An uncertain ACK write blocks later SAVEs of that instance; the ACK itself can be
  repeated. P3a will wire the command; none exists here.
- **Reboot:** `AWAITING_ACK` (and `AWAITING_ACK_RECORD_LOST`) are never auto-promoted;
  ACK persisted but reply lost -> CONSISTENT; torn ACK marker -> MARKER_CORRUPT (reconciliation).
  A lost acknowledged generation has priority over any in-flight state (no silent fallback).
  ADOPT of the awaiting generation is an explicit operator ACK; ADOPT of the acknowledged one
  discards the verified one; neither promotes corrupt/foreign records. A discarded older attempt
  surviving in the other slot no longer blocks the next ACK.
- **First SAVE** on an empty partition enters `AWAITING_ACK(0, 1)`; every interruption is
  distinguishable by marker + record; nothing is declared available before the ACK.
- **RAM:** store 5312 B, backend 16 B (unchanged); `LoadResult` 64 -> 68 B and `AckResult` 12 B are
  transient. No heap. Record V1 (1088 B) and A/B layout untouched.
- **Tests:** regression for the review finding (marker commit/set error, read-back error, power
  loss after publication, OK without ACK, N reboots, new SAVE cut at every write) at both the
  fake-storage and the NVS-stub level, with byte-for-byte checks of the acknowledged slot; ACK fault
  matrix; first-SAVE matrix; lost acknowledged generation; reconciliation; two consecutive errors.
  Mutation tests (gate removed, auto-ack) make the regressions fail. The stub still does NOT prove
  physical flash durability, NVS page recovery or SPI power-loss behaviour.
- P2.3 layout, manifest, flashing and OTA untouched. Nothing flashed, erased or run on the robot.

## Unreleased — P2.4 Dedicated NVS and persistent SAVE recovery (offline, no hardware) — 2026-10-02

Persistence layer only. **Not integrated** into the Controller: no command, no boot hook, nothing
reads a stored calibration into the motion path.

- **Dedicated partition.** `CalibrationRecordNvsBackend` uses `matdog_nvs` (0xFE0000 / 0x10000) by
  label: `esp_partition_find_first` (type/subtype/label, geometry pinned) ->
  `nvs_flash_init_partition("matdog_nvs")` -> `nvs_open_from_partition`. `begin()` is explicit and
  returns a `NvsInitStatus` (READY, PARTITION_MISSING, PARTITION_GEOMETRY_MISMATCH, NO_FREE_PAGES,
  NEW_VERSION_FOUND, INIT_FAILED, OPEN_FAILED); until READY every read is IO_ERROR and every write
  NOT_MODIFIED. Never `nvs_flash_init()`, never any erase/format, no retry, no repair.
- **Save marker V1** (`CalibrationSaveMarker`): 28-byte explicit little-endian blob, magic `MDMK`,
  schema 1, CRC-32, NVS key `M`. Fields: completed generation, begun generation, state
  (COMPLETED/PENDING). Not a journal; the 1088-byte CalibrationRecord V1 is unchanged.
- **SAVE protocol:** validate -> scan+classify -> PENDING marker (+read-back) -> write inactive slot
  -> full read-back -> COMPLETED marker (+read-back) -> `SaveStatus::OK`. Any outcome after the
  PENDING marker was published that is not full success blocks the instance (P2.1 block kept); the
  PENDING marker keeps refusing SAVEs across reboots until an explicit reconciliation.
- **Pure classifier** (`CalibrationPersistenceState`): 13 classes. Only CONSISTENT serves a record;
  a record newer than the marker is never promoted; marker attests G but only G-1 survives ->
  CONFIRMED_GENERATION_LOST (not healthy); erased partition == never initialized ->
  NEVER_INITIALIZED_OR_ERASED (no calibration, no motion). `planReconciliation()` defines the
  explicit recovery contract (ADOPT_VALID_RECORD / DECLARE_NOTHING_CONFIRMED); nothing executes it.
- **RAM:** `sizeof(CalibrationRecordStore)` 5312 B (unchanged: no new buffer), backend 16 B,
  transient `LoadResult` 28 -> 64 B (stack). No dynamic allocation.
- **Tests:** host stub extended (`nvs_open_from_partition`, `nvs_flash_init_partition`,
  `esp_partition_find_first`; default init, bare `nvs_open` and all erase calls are NOT declared so
  they cannot be called), power-cut and error injection at every mutating step, reboot model.
  Static audit pins the boundaries. The stub does NOT prove physical flash durability or NVS-internal
  page recovery.
- Layout P2.3, manifest, flashing and OTA untouched. Nothing flashed, erased or run on the robot.

## Unreleased — P2.3 Custom flash layout and flashing safety (offline, no hardware) — 2026-10-02

- **Layout `MATDOG_16M_2x5M_NVS_V1`** (`partitions.csv`, `PartitionScheme=custom`): nvs 0x9000/0x5000,
  otadata 0xE000/0x2000, app0 0x10000/5 MiB, app1 0x510000/5 MiB, ffat 0xA10000/0x5D0000,
  **matdog_nvs 0xFE0000/0x10000**, coredump 0xFF0000/0x10000. Default NVS precedes MATDOG NVS (the
  Arduino core erases the first nvs-subtype partition on a bad default NVS).
- `scripts/matdog_layout.py`: pinned contract, binary-table SHA-256, 5 MiB size gate (> 5,242,880 B
  refused, >= 4 MiB growth warning), write/erase-range check, migration contract (data only).
- **Manifest V2** adds `LAYOUT_ID`, `PARTITION_TABLE_SHA256` (of the table the build produced) and
  `APP_PARTITION_SIZE`; V1 manifests are rejected. The layout id string is compiled into the
  firmware and checked in the binary.
- `flash_app_only.sh` additionally verifies the table installed on the device, the target offset/size
  and the effective erase range before its single write. A device with the legacy table is refused
  (no bypass; migration is a separate procedure). `upload.sh` is now a refusing stub.
- OTA: `OtaPolicy::prepare()` refuses (`LAYOUT_NOT_CONFORMING`) when the running partition table is
  not the compiled-in contract. Authenticated layout declaration in the OTA metadata is a separate
  task (OTA metadata schema 2).
- **Not migrated**: the device still runs the legacy table. Nothing was flashed, erased or reset.

## Unreleased — TRUE 24-contact Full Calibration (LF V25 full-leg state machine × 4 legs) — 2026-09-30

**HARDWARE-VALIDATED 2026-10-01: TRUE FULL CALIBRATION 24/24.**
- Firmware `dfcecb670d0565d2db1a8152b6cd7ad230bdb87d`, BUILD_ID `dfcecb670d05`, app SHA256
  `5fe625cd…11c503da`.
- All four legs `HARDWARE_CONTACT_CALIBRATED` 6/6 on their first attempt; SAFE_OFF 13/13 verified.
- Fine-pass repeatability ≤ 4 ticks on all 24 contacts.
- Logged events: 23 transient (unconfirmed) temperature readings and 39 diagnostic held-speed
  transients; no held-role failure.
- Thin LOWER MAX scout margins: RF +6 and LH +13 ticks, from a systematic 3–6° LOWER MAX deficit
  against the URDF.
- Envelopes are not approved and the result is RAM-only (no persistence).
- Report and evidence hashes: `09_Logs/Validation_Reports/Full_Calibration_24_Contact_Hardware_2026-10-01/`.

Scope correction: **TRUE FULL CALIBRATION = 4 legs ×
3 joints × MIN/MAX = 24 contacts.** The "Full Leg" below (2026-09-29, PR #34) measured UPPER
MIN/MAX only, 2 of a leg's 6 contacts. It is superseded and is **not** Full Calibration. See
`09_Logs/Development_Log/2026-09-30_TRUE_24_CONTACT_FULL_CALIBRATION.md` and the V25 mapping
`…/2026-09-30_FULL_CALIBRATION_24_CONTACT_V25_TRACEABILITY.md`.

- **`FullLegCalibrationExecutor` (rewritten)**: the LF V25 `run_lf_state_machine` for every leg.
  PREFLIGHT → INITIAL_RECOVERY → PARKING → UPPER MIN/MAX → UPPER_HORIZONTAL → LOWER MIN/MAX →
  LOWER_FOLDED → HIP MIN/MAX → DIAGNOSTICS → RETURN_HIP/LOWER/UPPER → RESTORE_PARKING →
  CLEANUP/TORQUE_OFF. One phase per update, reported to the session in V25 order. COMPLETE only
  with 6/6 contacts + accepted V25 affine diagnostics + verified rest.
- **INITIAL RECOVERY**: every one of the 12 leg joints actively commanded to its promoted q0,
  one at a time (prime at present → RAM TorqueLimit 500 → torque on → move → V25 StableTargetGate
  → SAFE_OFF), then all verified at q0. It never moves a joint more than 64 ticks.
  `@CALIBRATION INITIAL RECOVERY <LEG> CONFIRM_Q0_RECOVERY` runs it alone (recovery-only: no
  probe, no evidence record; session + permit stay live).
- **Held prerequisites (V25 `prerequisites_for`)**: UPPER probe HIP/LOWER@q0; LOWER probe
  HIP@q0 + UPPER@90°; HIP probe UPPER@side clearance (LF 90/85, RF 85/90, rear 90/90) + LOWER
  folded; front legs keep the rear UPPER parked. A probe starts only with exactly that held set.
  Every held joint and one round-robin bystander are checked every tick (torque, GoalPosition,
  TorqueLimit, drift, status, current, temperature, telemetry age). Any violation fails
  closed to a verified SAFE_OFF of all 12.
- **Encoder direction = current-installation record, not the URDF (hardware correction,
  2026-10-01)**: the TRUE LF run resolved LF LOWER with the URDF custom `motorDirection` (+1),
  promoted to encoder polarity by CR0. "LOWER MIN" ran RAW DECREASING and drove the shank
  backward into the short-side (MAX) end-stop. The run failed closed with
  `EARLY_STALL_OUTSIDE_CORRIDOR`. A read-only witness then showed LF HIP inverted too.
  - Each leg joint's `encoder_direction` now lives in `MATDOG_SERVO_ALLOCATION.yaml`, with its
    source and evidence:
    - LF HIP/UPPER/LOWER: `CURRENT_HARDWARE_WITNESS`;
    - RF/RH/LH: `HISTORICAL_SLOT_UNCHANGED`, the slot's 2026-07 `PASS_DIRECTION_TEST`, since axes,
      servo type and mechanics are unchanged.
  - The exporter generates it into `GeometryJointRecord::encoder_direction`, with a
    `EncoderDirectionSource` per joint, and refuses a joint without a record. It never falls back
    to the URDF.
  - The record is in the profile provenance, so the frozen CR2-C package is refused on the new
    contract; fresh capture is the path.
  - The matrix differs from the URDF on all eight HIP/LOWER joints.
  - CR0, source precedence, bootstrap §11 and the audit are amended. The URDF and Geometry V5
    are not changed and not rerun.
- **Held-role supervision = LF V25 `ActivelyHeld` (hardware correction, 2026-09-30)**: the
  post-V25 held-joint speed abort (`HELD_JOINT_SPEED`, |speed| > 40 raw × 2 samples) is removed,
  and nothing replaces it. On hardware it aborted LF UPPER MAX while every held joint was inside its
  10-tick hold. An already-held joint fails on telemetry, status, hard current, confirmed
  temperature, TorqueEnable/TorqueLimit/GoalPosition readback and drift > 10, exactly as
  `validate_lf_role_observation`. `LF_HELD_MAX_SPEED_RAW = 4` stays the StableTargetGate before a
  joint is held and the INITIAL_RECOVERY settle. New evidence naming the exact motor:
  `CALIBRATION_HELD_ROLE_FAILURE` (once per failure) and, diagnostic only,
  `CALIBRATION_HELD_SPEED_TRANSIENT` (rising edge, ≤ 32 per run).
- **`CalibrationSequencePlan` (new)**: the second authorization object. Poses per leg, generated
  by `matdog_full_calibration_sequence_geometry_v5.py` from four collision-free validation
  artifacts (every segment of every leg's sequence on the SHA-pinned URDF/meshes). Rear LOWER fold
  −455 ticks (V25 −990 gives 0.04 mm body clearance on the rear legs). `SafeActuatorPolicy`: new
  `CALIBRATION_SEQUENCE_MOVE` (phase table, tick re-derived) and `CALIBRATION_TORQUE_LIMIT`
  operations; sequence probes go through their own door (`evaluateSequenceProbe`: phase ==
  endpoint, prerequisites verified, corridor). `isExecutable()` unchanged.
- **RAM TorqueLimit 500 (V25 `prepare_motor`)**: `ServoBus::writeReviewedRamTorqueLimit()`, the
  one raw register write (RAM 48, readback-verified, no argument). Never restored (V25).
  `ServoBus::readControlFeedback()` reads TorqueEnable/Goal/TorqueLimit + feedback + status in
  two block reads.
- **ContactProbeEngine**: `start_torque_verified`, the V25 `stop_pressure` release, and
  `TORQUE_LIMIT_CHANGED` / `SERVO_STATUS_FAULT` / `GOAL_READBACK_MISMATCH`.
- **ContactProbeEngine — the LF V25 coarse contact scout restored (corrective commit; closes PR
  #35 D6 "no coarse scout, inherited from #34")**: every one of the 24 searches is now V25
  `measure_lf_contact_side_efficient` stage for stage:
  - BASELINE: one 64-tick moving-current move from the present pose (≥ 6 samples, 12 s).
  - COARSE scout: 64-tick steps from the baseline end, never clamped at the entry; the static
    corridor applies; pre-corridor steps are free-space transit, where a stall is EARLY_STALL.
  - RELEASE (GoalPosition := the scout, read back), then BACKOFF 96.
  - FINE 1 (8), RELEASE, BACKOFF 96, FINE 2 (8), RELEASE; repeatability |fine 1 − fine 2| ≤ 16.

  Both fine passes are judged against the scout: the adaptive corridor (scout − 32), the
  one-fine-step lag bypass (friction/chamfer plateau) and the V25 kinematic-plateau
  confirmation. Evidence is `coarse_tick` = scout (reference only), `fine_tick_1/2` = the fine
  passes. Diagnostics use the midpoint of the fine passes and the envelope the second fine pass;
  the scout enters neither. New: `SCOUT_MISSING`, `BASELINE_PASSES_GUARD`; phases
  `BASELINE_*`, `RELEASE_VERIFYING`; stages `BASELINE`, `COARSE_SCOUT`, `RELEASE`. Serial:
  `CALIBRATION_SEARCH … kplateau= scout=`, `CALIBRATION_FULL_LEG_CONTACT … scout= fine1= fine2=`,
  export `scout_tick= fine1_tick= fine2_tick=`. Known V25 property, risk R2: the scout's reach
  near the guard depends on its 64-tick grid phase and hence on the fresh q0 (development log §3).
- **Backoff = V25 StableTargetGate** (closes review H1): a backoff is arrived only after ≤ 12
  ticks, |speed| ≤ 4, 4 consecutive samples and ≥ 400 ms (`SearchSettleGate`, reset by any bad
  sample). Only then are the current recovery and the next fine pass allowed. TorqueEnable and
  the whole readback are checked on every backoff sample.
- **Final bounded partial coarse-scout step (deliberate current-installation deviation, NOT V25).**
  When the next 64-tick scout step would pass the existing guard, ONE final partial step (< 64
  ticks) targets the guard itself; it is never beyond and never repeated. It removes V25's
  grid-phase blind gap before the guard, where the measured LF UPPER MIN stop (raw 1468, margin
  −3…+1 at q0 2090) fell. The guard, step size, corridor and fine passes are unchanged. Reach is now
  guard − 18 (URDF + 46) for every q0; the LF UPPER MIN margin is +21. Tested on all 24 endpoints
  (22 of 24 need it at guard − 18).
- **Runtime PresentTemperature over-limit confirmation, ported from LF V25 `port.rs`** (hardware
  finding 2026-09-30). The first TRUE LF run aborted in PARKING on ONE M42 sample > 70 °C; M42
  read 32 °C a second later.
  - Now a sample > 70 °C is re-read directly twice on the same servo, each read after 50 ms.
  - ≥ 2 of 3 over the limit aborts as before; exactly 1 is a transient (logged, the last normal
    value used) and the run continues; a failed confirmation read aborts (fail closed).
  - `calibration/ThermalConfirmation.*`, `ServoBus::readPresentTemperatureDirect()`, applied by
    the Controller to every Full-Leg sample; `CALIBRATION_THERMAL_CONFIRMATION …` log line.
  - Only temperature is confirmed; every other fail-closed check is unchanged. The EEPROM
    MaxTemperature (0x0D = 70) stays a preflight check.
- **Search telemetry timeout 2 s** (V25 `TELEMETRY_TIMEOUT`; closes review M1): was the inherited
  3 s, for the search stages and the backoff deadman.
- **Recentred installation, proven**: every calibration raw target is the fresh promoted q0 +
  direction · q. For two installations with different per-joint mounting offsets, identical URDF
  commands, all 24 corridors, every prerequisite pose and the park move by exactly Δq0
  (`test_recentred_installation_translation`). The audit refuses the raw centre 2048 in every
  calibration target unit.
- **Finalizer / evidence**: 6 contacts recorded per leg; UPPER/LOWER/HIP envelopes;
  `contacts_expected=6` and `contacts_accepted` (0 unless 6); four-leg result only at 24/24.
  Export `format=2`: `LEG` + `LEG_CLOSE`, six `CONTACT`, three `DIAG`, and the `END` line with
  `total_contacts_expected=24 total_contacts_accepted=…`. Lines are never truncated (512-byte
  buffers, worst case host-tested).
- **Runner** `scripts/calibration_hw_session.py`: phases `prepare / q0 / recover / legs / all`.
  `legs` needs `--confirm-operator-go`. It requires 6/6 per leg and the 24/24 export; anchored
  whole-line records only.
- **Gates**: host suites (executor end-to-end on four legs + ~30 adversarial cases, the V25
  search trace of all 24 endpoints, 24-profile plan matrix, 24-contact finalizer), static audit
  (incl. plan-data re-derivation and the coarse-scout pins), Safe Actuator / LED / DALY mutation
  suites, and behaviour mutations (staged search, coarse scout, orchestration).

### LED — DALY informational alarm bit is not a charging fault (presentation only)

- Live 2026-09-30: an attended KEY-OFF charge (SOC 55 %, MOS on) showed `CHARGING_FAULT` for
  `alarms=0000 0000 0000 0010`. The DALY app names that bit "GPS or soft switch turn off MOS".
- `status::dalyAlarmBlocksChargingPresentation()`: word 3 bit **0x0010 alone** no longer shows
  `CHARGING_FAULT`. Words 0–2 ≠ 0 or any other word-3 bit still do.
- Unchanged: raw alarm words (`@BMS STATUS`), `DalyBms` `alarms_clear` (the KEY/MOS write gate),
  DALY protection, MOS, every non-LED gate. Audit-pinned; LED mutation suite extended.

## Unreleased — staged calibration endpoint search (LF V25 oracle) — 2026-09-29

**OFFLINE-VALIDATED, FLASH-READY; HARDWARE VALIDATION PENDING. Never run on hardware.**
Supersedes the contact+16 / URDF-clamp probe (`e5c0a3c`, `67cd3cb`, entry below). The clamped
run (1489) arrived 4 ticks short, like every earlier target. The operator then found the real
LF_UPPER MIN stop by hand, torque off: **~23 ticks past the Geometry V5 contact / URDF limit**.
No single target at or near the model contact can witness that stop, and "no progress 4–5 ticks
short" is servo settling, not contact. The search is now a port of the only
hardware-validated calibrator's *behaviour*, LF V25 (`matdog.rs`), made generic over
LF/RF/RH/LH; see
`09_Logs/Development_Log/2026-09-29_FULL_CALIBRATION_V25_ORACLE_TRACEABILITY.md`.

- **Search corridor** (`actuator::resolveCalibrationSearchCorridor`): entry = URDF limit − 64,
  guard = URDF limit + 64 along the probe direction (V25 `GUARD_OVERSHOOT_TICKS`,
  `contact_acceptance_bounds`). Geometry V5 contacts and the URDF domain are unchanged. The
  corridor is a calibration-search bound only.
- **SafeActuatorPolicy**: `REJECT_CALIBRATION_SEARCH` covers a search flag on any operation other
  than `CALIBRATION_CONTACT_PROBE`, and a search target outside [opposite URDF limit, guard].
  `REJECT_MOTION_PROFILE` covers `MotionProfile::CALIBRATION_SEARCH` on any operation other than
  CONTACT_PROBE / AUXILIARY_MOVE (never `POSITION_COMMAND`, stand, gait, first motion). Both are
  checked before any route can accept. The legacy µrad path (`REJECT_TARGET_OUTSIDE_URDF_LIMITS`,
  contact check) is unchanged for everything else.
- **Speed profile**: `ServoBus::writeGoalPosition(id, tick, GoalMotionProfile)`:
  BOUNDED 40/10 (unchanged default) or SEARCH_ENVELOPE 160/8 (V25 `GOAL_SPEED`/`ACCELERATION`),
  plumbed through `ActuatorRuntime` → `ActuatorBackend`. An unknown profile is never written.
- **ContactProbeEngine** (rewritten): COARSE_TRANSIT (64-tick steps, clamped at the entry) →
  FINE_SEARCH (8-tick target steps) → contact #1 → BACKOFF 96 (current must recover to the
  transit baseline, median + max(4·MAD, 5)) → FINE_SEARCH pass 2 → contact #2 within 16 of #1.
  A pass-2 candidate > 8 ticks short of #1 is a friction plateau and is stepped past; pass 2
  accepts up to 32 ticks HOME-ward of #1. `ContactSearchDetector` ports V25's
  `HybridContactDetector` rule for rule: 4 startup samples, 24 ticks travel, progress ≤ 2,
  |speed| ≤ 10, goal error > 10 inside / > 16 outside, target ahead, 3 samples. Stalls outside
  the corridor are `EARLY_STALL_OUTSIDE_CORRIDOR`. Current is never part of contact admission.
  Other V25 figures: 20 ms consumption cadence, 900 ms settle window, tracking limit
  max(step + 4, 16), hard current ≥ 200 raw, temperature > 70 °C. A step past the guard is never
  issued: `NO_CONTACT_BEFORE_GUARD`. Every failure after TorqueEnable is SAFE_OFF_REQUIRED.
- **Full Leg executor/plan**: per-side `CalibrationSearchCorridor`s replace approach/backoff µrad
  and overtravel (`REJECT_SEARCH_CORRIDOR`). Evidence ticks = pass 1 / pass 2 contacts. The
  auxiliary park runs at 160/8 with the travel-aware deadman at V25's 80 ticks/s, arrival 10.
  The backoff arrival is 12. The parking matrix, SAFE_OFF paths, finalizer and
  HARDWARE_CONTACT_CALIBRATED semantics are unchanged.
- **Observability**: ARMED prints `CALIBRATION_FULL_LEG_SEARCH_CORRIDOR side=… entry=… guard=…`.
  Every step/state change prints `CALIBRATION_SEARCH …` (stage, target, pos, beyond_contact,
  speed, current, baseline, p1/p2, bypass). `PROBE_FINAL` and STATUS carry the same fields.
- **Removed**: `kContactProbeMaxOvertravelTicks`, `resolveContactProbeApproachToRaw`,
  `REJECT_PROBE_OVERTRAVEL`, and the contact+16 / URDF-clamped single target. No compatibility
  path is left.
- **Not ported from V25 (documented in the traceability file)**: RAM TorqueLimit 500; the coarse
  contact scout; `confirm_kinematic_plateau`; per-sample goal/status readback; holding
  HIP/LOWER at q0; drift monitoring of the other joints; the 400 ms stable-target gate.
- **Runner**: `scripts/calibration_hw_session.py` is a one-shot, fail-closed session:
  build/manifest check → app-only flash → no-reset serial → signature/MAINTENANCE → SAFE_OFF
  13/13 → Q0 CAPTURE (half-tooth 82 stop vs CR2-C) → PROMOTE 12 → LF, RF, RH, LH → SAFE_OFF 13/13
  → EVIDENCE EXPORT check. Terminal detection is exact
  `CALIBRATION_FULL_LEG_RESULT leg=<LEG> verdict=… failure=…` only. Tests:
  `test_calibration_hw_session.py`.
- Tests:
  - `test_contact_probe_engine` (10 148 checks) on a kinematic ST3215 model
    (`kinematic_servo_sim.h`);
  - `test_full_leg_calibration_executor` (4 288);
  - plan/engine/q0-promotion/runtime/first-motion/policy suites updated;
  - `check_calibration_search_boundaries` plus 17 static mutation cases;
  - `test_calibration_search_behaviour_mutations.py`: source mutations, each of which must make
    the host tests fail.

## Unreleased — URDF-clamped contact-probe overtravel (hardware finding #2) — 2026-09-29

**SUPERSEDED by the staged endpoint search above; the mechanism below was removed.** Flashed as
`67cd3cb` and run once on LF. The clamped target (1489) arrived 4 short (1493), and the real
stop proved to be ~23 ticks past the contact, beyond any single URDF-bounded target.

*Original entry:* **OPERATOR-APPROVED, OFFLINE-VALIDATED; hardware re-test pending.** With the motion budget fixed
(`b646631`), LF's MIN first approach reached its stop and stalled at tick 1500, but the stop sits
4–5 ticks short of the Geometry V5 contact (target 1495). Pass 2 ended within the 4-tick arrival
tolerance (1499), so it read as arrival: `NO_CONTACT_DETECTED`. The operator confirmed the leg
pressed on the intended stop both times.

- `actuator::kContactProbeMaxOvertravelTicks = 16` and
  `resolveContactProbeApproachToRaw()`: the only way to command past a contact. It resolves the
  canonical contact through the URDF-checked resolver, then moves by min(16, room to the URDF
  joint limit) raw ticks in the side's approach direction. The room is the furthest tick that
  still converts back inside the URDF domain (`resolveRawToUrdfQ`). It never crosses the URDF
  limit and never wraps; asking for more than 16 returns `REJECT_OVERTRAVEL`. 16 is a ceiling,
  not a travel amount. For every UPPER joint today the room is **4 ticks (MIN)** and
  **6 ticks (MAX)**, independent of q0.
- The ceiling field flows plan → executor → probe → engine → policy (default 0). Both approach
  passes use the clamped point for the command and for arrival; the backoff never does. The plan
  sets `kFullLegApproachOvertravelTicks = 16` (ceiling), statically bounded by the maximum, and
  records per side `contact_tick`, `target_tick`, `urdf_limit_tick` and
  `applied_overtravel_ticks`.
- `SafeActuatorPolicy`: `REJECT_PROBE_OVERTRAVEL` for any non-CONTACT_PROBE command carrying the
  ceiling, checked before any route can accept (including the future stand/gait
  `POSITION_COMMAND`). For CONTACT_PROBE the anchor must be exactly the canonical contact. The
  commanded tick must independently convert back inside the URDF domain
  (`REJECT_TARGET_OUTSIDE_URDF_LIMITS`) and equal the policy's own clamped re-derivation. The
  execution engine also refuses the ceiling on other intents.
- Unchanged: Geometry V5 contacts (still the evidence reference), URDF limits, backoff, arrival
  tolerance, stall window/progress, repeatability 16, aux parking, envelopes/JointLimits.
- ARMED prints `CALIBRATION_FULL_LEG_PROBE_BOUND side=MIN|MAX contact_tick=… target_tick=…
  urdf_limit_tick=… applied_overtravel_ticks=… ceiling_ticks=16 …`.
- Revision history: `e5c0a3c` first let the allowance reach contact+16 past the URDF limit. It was
  flashed but never ran a motion. On the operator's decision it was revised to clamp at the URDF
  limit before any hardware use.
- Tests: policy/engine cases (four UPPER joints, MIN and MAX, applied 4/6 from a hand-computed
  oracle; the clamp is tight; the unclamped contact+16 is refused; >16 is refused at every layer;
  16 is only a ceiling; CONTACT_PROBE only; the backoff cannot carry it); kinematic cases (a stop
  4 ticks short without the allowance reproduces `NO_CONTACT_DETECTED`; stops 4–5 ticks short
  stall on both passes of both sides on all four legs, target-to-stop 8–9 MIN / 10–11 MAX; with
  no stop the run fails at the clamped point and never goes further); plan pins; an audit rule
  and ten mutation cases.

## Unreleased — Full-Leg motion budget fix (hardware finding) — 2026-09-29

**PARTLY SUPERSEDED.** The travel-aware deadman stays, and the backoff and auxiliary park use it at
V25's 80 ticks/s. The probe's steps are now monitored by the staged search, and
`PROBE_FINAL` has new fields (entry above). Verified on hardware: the MIN first approach reached
the stop instead of timing out (`b646631` run).

*Original entry:* **HARDWARE-DISCOVERED DEFECT, FIXED OFFLINE; hardware re-test pending.** Both LF Full-Leg
attempts of the 2026-09-29 session (`14881cd`) ended `UPPER_MIN_PROBE_FAILED`: every monitored
Full-Leg move had the fixed 12 s deadman budget, but `ServoBus::writeGoalPosition()` commands the
bounded 40 ticks/s (~3.5 deg/s), so no move could exceed ~480 ticks (~42 deg). The Geometry V5
UPPER contacts need ~590 ticks (MIN first approach) and up to ~1980 (MAX first approach); the
probe hit `MOTION_TIMEOUT` before reaching the stop. The offline suites teleported the synthetic
servo, so travel time was never modelled.

- `MotionDeadmanConfig::nominal_travel_ticks_per_s` (default 0 = unchanged fixed budget). When
  set, the first in-range sample fixes the start and the budget becomes `motion_timeout_ms` plus
  the nominal travel time at that rate; fixed once, so a late sample can only shorten it. Stall,
  telemetry-age, torque and communication checks are unchanged; so are the write speed, travel,
  contact targets and repeatability tolerance.
- `Controller::begin()` sets it to `servo::ServoBus::kBoundedWriteSpeed` for the three Full-Leg
  deadman configs only; the 16-tick DIRECTION_VERIFY keeps the fixed 12 s. Pinned by
  `check_full_leg_calibration_wiring` plus four mutation cases.
- Observability: `FullLegCalibrationExecutor::probeStatus()`; `@CALIBRATION FULL LEG STATUS`
  prints `CALIBRATION_FULL_LEG_PROBE …`, and the terminal output prints
  `CALIBRATION_FULL_LEG_PROBE_FINAL …` just before `CALIBRATION_FULL_LEG_RESULT`, so a probe
  failure's cause (e.g. `MOTION_TIMEOUT` vs `NO_CONTACT_DETECTED`) is visible on hardware.
- Tests: six `test_motion_deadman` cases; a kinematic 40 ticks/s executor rig that reproduces
  the hardware signature bit for bit with the old budget (probe `MOTION_TIMEOUT`, pass 1, two
  writes) and completes all four legs at the physical stops with the new one.

## Unreleased — current-boot q0 promotion — 2026-09-29

**IMPLEMENTED / OFFLINE-VALIDATED. Never run on hardware.** `@CALIBRATION Q0 PROMOTE
CONFIRM_CURRENT_INSTALLATION` used to rehydrate the frozen CR2-C package, so a fresh capture
never reached `JointTransformTable`. It now promotes the twelve candidates of the current-boot
capture.

- `CalibrationQ0CaptureSession::freshCapture()` exposes the capture as a plain-data
  `FreshQ0Capture`; `prepareFreshQ0Evidence` runs it through the shared CR3 accept-and-promote
  rule, all twelve or none, and `JointTransformTable::admit` replaces the previous q0 in place.
  `prepareCurrentQ0Evidence` (frozen CR2-C) stays as a regression oracle only; the static audit
  forbids any production use.
- PROMOTE is refused while a capture, a session, an armed Full Leg run or motion is active
  (`BUSY`); `SESSION START` refuses (`CURRENT_BOOT_Q0_NOT_PROMOTED`) unless the table holds exactly
  the current capture's q0. Reply: `CALIBRATION_Q0_PROMOTE=OK admitted=12/12
  source=CURRENT_BOOT_CAPTURE capture_session=<n>`. RAM only; no EEPROM/NVS write, no motion.
- New host suite `test_cr3_q0_fresh_promotion` (338 checks) and twelve static-audit mutation
  cases. The four-leg runbook now promotes the current capture and treats CR2-C as comparison
  only.
- No persistence exists: **Calibration Persistence V1** is the gate after the hardware Full
  Calibration PASS ([`ROADMAP.md`](../../01_Docs/02_Architecture/ROADMAP.md)).

## Unreleased — Full Calibration generalized to LF → RF → RH → LH — 2026-09-29

**IMPLEMENTED / OFFLINE-VALIDATED. Never run on hardware.** One `ROBOT_POWERED` build can
calibrate all four legs in one session.

- `@CALIBRATION SESSION START <LF|RF|RH|LH> CONFIRM_CURRENT_Q0` and
  `@CALIBRATION FULL LEG <LF|RF|RH|LH> CONFIRM_FULL_CALIBRATION` are strict four-token
  commands; buses, identities, MIN/MAX endpoints and parking are derived (canonical allocation →
  Geometry V5), not typed. Parking: LF→LH_UPPER, RF→RH_UPPER, RH none, LH none. The
  `DIRECTION_VERIFY LF_UPPER +16` diagnostic stays exact and LF-only.
- Evidence lifecycle closes at COMPLETE (contacts → envelopes → limit admission →
  `completeSession()` → permit revoked → authority NONE) into a RAM record per leg;
  `@CALIBRATION EVIDENCE EXPORT` prints all four deterministically.
- **`HARDWARE_CONTACT_CALIBRATED` ≠ `FINAL_OPERATIONAL_ENVELOPE_ACCEPTED`.** No approved
  stand/gait workspace exists, so production envelope parameters are unapproved placeholders and
  hardware runs end at the first level; 0 of 12 JointLimits are admitted.
- Runbook: [`FULL_CALIBRATION_4LEG_HARDWARE_RUNBOOK.md`](FULL_CALIBRATION_4LEG_HARDWARE_RUNBOOK.md).
  Log: [`2026-09-29_CALIBRATION_FULL_4LEG.md`](../../09_Logs/Development_Log/2026-09-29_CALIBRATION_FULL_4LEG.md).

## Unreleased — LED V2 focused hardware validation recorded — 2026-09-26

**Focused HARDWARE PASS; live charging-specific animations remain TO_TEST.**
This entry records the completed operator session; the repository closeout itself is
one docs-only commit with no rebuild, flash, serial access or merge.

- Exact flashed source: `88062e1a1217f288ebcc161c6213dbb543ea6f8a`, build ID
  `88062e1a1217`, ROBOT_POWERED, OTA ingest 1; application 1,029,232 bytes at
  `app0 @ 0x010000`, SHA256
  `772a046e1b2d61888dba0ab7ddc759be13bbd4a33d1722b6be5285c313aac56b`.
  Application-only flash and independent digest verification passed. The later docs
  commit and any eventual merge commit are separate from this firmware provenance.
- BOOTING breathing passed (perceived white / slightly cyan-ish; hue not calibrated).
  Servo preflight passed 12/12 with `torque_enable=0`; system transitioned to READY
  and authority stayed NONE. No actuator or calibration motion occurred.
- Real cached 75.5% SOC produced nine green LEDs, noon through eight o'clock.
  Noon/clockwise order and `@LED SOC TEST` fill/drain, self-termination and automatic
  return to the real nine-segment bar at 75.2% passed physically.
- Live charging pulse, charging-at-100% tail and real charging-fault presentation
  remain TO_TEST. SOC TEST displays fixed bars and does not simulate CHARGING.
  FULL/warning/critical facts still have no producer; true FULL policy remains
  FUTURE / TO_DESIGN, and SOC 100% never proves FULL. Existing RF/OTA and autonomous/
  unattended charging gaps remain open; full calibration is a separate workstream.

Full evidence and validation boundary:
[`2026-09-26_LED_STATUS_MANAGER_V2_HW_VALIDATION.md`](../../09_Logs/Development_Log/2026-09-26_LED_STATUS_MANAGER_V2_HW_VALIDATION.md).
The following implementation entries preserve their status before this hardware session.

## Unreleased — LED V2 reserved battery facts — 2026-09-26

**IMPLEMENTED / OFFLINE-VALIDATED. Physical LED validation remains TO_TEST.**

- Reserve `battery_warning` and `battery_critical` in the presentation API and
  snapshot; both default false and have no production producer or invented threshold.
- Warning breathes amber at 6..20 over 3 s, between DEGRADED and WIFI_CONNECTING.
  Critical breathes red at 6..30 over 3 s, between CHARGING_FAULT and DEGRADED.
- `@LED STATUS` exposes both facts. Host tests and static/mutation audits enforce
  the final priority, effects and absence of a production battery-policy producer.
- Existing SOC, charging, diagnostics, USB_ONLY and safety contracts remain unchanged.
  Full offline checks and both clean builds pass; no hardware or flash was involved.

## Unreleased — LED Status Manager V2 final — 2026-09-26

**IMPLEMENTED / OFFLINE-VALIDATED. LED V2 hardware validation remains TO_TEST.**

- READY now displays completed twelfths of fresh BMS-reported SOC, starting at noon
  and filling clockwise through physical `{1,2,3,4,5,6,7,8,9,10,11,0}`. Quantization
  is `floor(clamp(SOC,0,100)*12/100)`, with no upward rounding at float boundaries.
- Cached DALY `CHARGING` adds a subtle pulse on the next segment; at reported 100%,
  the final segment keeps pulsing. Charging with a cached alarm breathes red.
  Freshness requires a valid sample, latest comm OK and age at most 5000 ms, sharing
  the existing telemetry bound. Invalid/stale SOC breathes amber.
- BOOTING changes to subtle white breathing. Existing fault/OTA/calibration/degraded/
  Wi-Fi colors and envelopes remain unchanged. All subtle effects use 6..20 over 3 s.
- Reserved verified charge-complete rendering has no production producer;
  SOC 100% never selects FULL. Charge-completion policy remains FUTURE / TO_DESIGN.
- Added bounded `@LED SOC TEST` (600ms levels, full pause, 16.8 s total) and cached
  renderer facts in `@LED STATUS`. The existing native `@LED TEST` chase is preserved.
- Real policy and driver/manager host tests, USB_ONLY transport checks and mutation
  audits cover the change. Both firmware profiles compile. No hardware was accessed.

Evidence and remaining physical checks:
[`2026-09-26_LED_STATUS_MANAGER_V2_FINAL.md`](../../09_Logs/Development_Log/2026-09-26_LED_STATUS_MANAGER_V2_FINAL.md).

## Unreleased — network-path diagnosis, no reflash — 2026-09-26

Documentation only; same flashed candidate (`build_id=c45858c532e9`, re-confirmed unchanged).
Follow-up to the entry below: diagnosed why `GET /status`/OTA network reachability failed, instead
of assuming RSSI alone.

- `ip neigh show 192.168.1.136` on the client machine reports **`FAILED`** — ARP never resolved a
  MAC address at all, while the router and other LAN devices resolve normally. This rules out a
  local firewall (ARP is below any packet-filtering layer) and is a stronger finding than "weak
  signal, reduced throughput."
- 6 RSSI reads this session: **-89 to -93 dBm**, consistently at/below the -90 dBm threshold treated
  as too weak for a meaningful transport test. Classified **`RF_LINK_TOO_WEAK_FOR_MEANINGFUL_TRANSPORT_TEST`**;
  network validation stopped there per instruction, with no firmware change and no request for any
  physical RF intervention.
- **`WIFI_TICK` re-characterized favorably**: 5 steady-state reads while `CONNECTED` showed
  `last_us` of 3-19 µs — tiny, matching the bounded/non-blocking design intent. The previously-flagged
  `max_us=45612` (45.6 ms) stayed byte-identical across every reading, consistent with a one-time
  connection-sequence cost, not a recurring one.

Full record:
[`09_Logs/Development_Log/2026-09-26_HARDWARE_VALIDATION_CANDIDATE_V3.md`](../../09_Logs/Development_Log/2026-09-26_HARDWARE_VALIDATION_CANDIDATE_V3.md)
(follow-up section).

## Unreleased — first hardware flash + validation (candidate V3) — 2026-09-26

**HARDWARE VALIDATED (partial — see below). No motion, no torque, no EEPROM/DALY write.**
First-ever real flash of a `ROBOT_POWERED` + `OTA_INGEST_ENABLED=1` candidate
(`SOURCE_HEAD=c45858c532e97a5a104fb8330ad9cd909b75663e`,
`APPLICATION_SHA256=13a1e9504e950d3d4bbc14ed78032019c8bf8bacb75804ca57555069787d5b71`), application
partition only, hash-verified at write time and independently by a post-write `verify-flash`.

- **Fail-closed properties confirmed live on hardware**: no actuator authority ever granted, no
  torque ever enabled (every servo preflight record shows `torque_enable=0`), no limits/transforms
  admitted, `hardware_motion_authorized=NO`, Web server `started=NO` at boot, OTA update gate refused
  with no session ever started.
- **IMU, BMS, servo preflight (12/12 PASS, zero mismatches)**: all `HARDWARE_VALIDATED` for the
  checks run, superseding their prior `HARDWARE_TO_TEST` classification.
- **Wi-Fi**: first-ever real association for this project — connected on the first attempt, DHCP-
  assigned. RSSI measured at -92/-93 dBm (very weak) and `WIFI_TICK max_us=45612` (45.6 ms, the
  first real measurement of this figure) are both recorded as genuine findings, not glossed over.
- **I7/I8 network transport, first hardware exercise**: the `@WEB SERVER START/STOP/START/STATUS`
  lifecycle (the I7/I8 hardening round's fix) completed cleanly with the Controller thread staying
  responsive throughout. `GET /status` and the OTA challenge/authentication path from a network
  client could **not** be validated this session — the client machine had a direct route to the
  robot's subnet but neither `ping` nor `curl` reached it, most likely due to the weak RSSI above;
  not investigated further, `TO_TEST`.

Full record:
[`09_Logs/Development_Log/2026-09-26_HARDWARE_VALIDATION_CANDIDATE_V3.md`](../../09_Logs/Development_Log/2026-09-26_HARDWARE_VALIDATION_CANDIDATE_V3.md).

## Unreleased — I7/I8 network transport hardening — 2026-09-25

**Implemented, compiled and offline-tested.** Six concrete findings from operator review of the
I7/I8 implementation below, all addressed:

- **OTA-ingest validation override**, so the ONE hardware-validation candidate can carry a real,
  reachable OTA writer without a second later flash, while the source default stays `0`:
  `MATDOG_OTA_INGEST_VALIDATION=1` (new `scripts/build.sh` input) and `MATDOG_FLASH_OTA_INGEST=1`
  (new `scripts/flash_app_only.sh` input), both loud and both requiring explicit authorization —
  `scripts/build_manifest.py` gained `OTA_INGEST_ENABLED` as a second, fully independent
  authorization axis alongside `HARDWARE_PROFILE`, never inferred from it.
- **Mailbox stale-response fix**: a third semaphore (`slot_free_`) plus a new pure, host-tested
  decision core (`src/network/HttpMailbox.h`, `scripts/tests/test_http_mailbox.cpp`, 27 checks)
  close a real bug — a timed-out `dispatch()`'s late-computed response could previously leak
  forward and be wrongly consumed by a later, unrelated request.
- **Start/stop lifecycle fix**: `stop()` now deletes every semaphore `start()` creates (previously
  leaked two handles per START/STOP cycle); `start()` releases whatever it already allocated on
  every partial-failure path. New static-audit structural checks, mutation-verified.
- **OTA challenge hardening**: `issueChallenge()` is now idempotent while a still-valid challenge is
  outstanding, so a repeated unauthenticated call can no longer displace a legitimate client's
  in-flight nonce (an availability weakness adjacent to the nonce-consumption bug already fixed in
  the previous entry). 3 new/replaced adversarial tests, mutation-verified.
- **`/status` threat model and OTA security model documented explicitly** in
  `src/network/HttpTransport.h`: `/status` stays unauthenticated by deliberate, justified choice
  (reachable only after a MAINTENANCE-mode USB `@WEB SERVER START`, carries no secret, and adding
  auth here was rejected as either reusing the OTA credential — backwards from "write must stay
  stronger than read" — or inventing a second, unjustified credential system); the OTA transport's
  exact protections and non-protections (no TLS, no confidentiality) are stated plainly with no
  guarantee implied that does not exist.

Full record:
[`09_Logs/Development_Log/2026-09-25_I7_I8_HARDENING.md`](../../09_Logs/Development_Log/2026-09-25_I7_I8_HARDENING.md).

## Unreleased — I7/I8 network transport implemented — 2026-09-25

**Implemented, compiled and offline-tested. NOT flashed. NOT hardware-tested. Server disabled at
boot; ingest still compiled out by default.** Supersedes the earlier "I7 reconsidered" / "I8
reconsidered" entries below, per the operator's "FINAL PRE-FLASH CONSOLIDATION" instruction, which
corrected the premise those entries were blocked on: the 96-byte USB CDC line buffer blocks
streaming firmware through the line-oriented command parser, not the OTA transport architecture in
general — an HTTP transport's request body never touches `CommandRouter::handleLine()` at all.

- **New `src/network/HttpTransport.h/.cpp`** — an `esp_http_server` adapter, the CONTROL/
  AUTHORIZATION plane in front of the one existing `OtaManager`/`OtaPolicy`/`OtaEspBackend` writer.
  Three endpoints: `GET /status` (I8, read-only), `GET /ota/challenge` (I7), `POST /ota/update`
  (I7). A single-slot FreeRTOS binary-semaphore mailbox hands each httpd-task request to the one
  Controller thread and back, bounded by a 3000 ms timeout (fails closed to `503` on timeout,
  never blocks either task indefinitely). `start()`/`stop()` are never called from
  `Controller::begin()` — reachable only from the new MAINTENANCE-gated `@WEB SERVER
  START\|STOP\|STATUS` command.
- **New `src/update/OtaSession.h/.cpp`** — a pure, host-linkable HMAC-SHA256 challenge/response
  authentication/session layer between the transport and `OtaManager`. Single-use server-issued
  nonces (no clock-sync dependency), a fixed-width signed payload (nonce + schema/size/sha256/
  build_id), configurable challenge TTL and activity timeout. Two real bugs found and fixed by its
  own 35-check adversarial suite before being trusted: a nonce-consumption availability bug (a
  mismatched nonce was burning the real outstanding challenge — a DoS against the legitimate
  client) and a `build_id` tail-byte nondeterminism bug in the signed payload.
- **New `src/update/Hmac256.h/.cpp`** — HMAC-SHA256 (RFC 2104/FIPS 198-1) built on the existing
  reviewed `Sha256`. Verified against RFC 4231's official test vectors (11 checks), not
  self-consistency only.
- **New `src/config/OtaCredentials.h` / `OtaCredentials.local.h.example`** — the OTA HMAC shared
  secret, following the exact same resolution order, gitignore discipline and
  exactly-one-use-site audit enforcement as `WifiCredentials.h` (W1). A separate secret from the
  Wi-Fi passphrase.
- **`GET /status` field coverage** — system/source identity, module health, Wi-Fi state, BMS
  cached telemetry, IMU stream/rv summary, LED presentation, actuator readiness (via
  `ServiceReadiness`), calibration readiness/state, OTA status/provenance. Strictly read-only; no
  actuator-write API of any kind.
- **New static-audit check** `check_http_transport_boundaries()`: `Hmac256`/`OtaSession` stay
  host-linkable; the ESP-IDF HTTP server API is confined to `HttpTransport.cpp` (mirroring the
  existing OTA-API-confinement rule); `Controller::begin()` never starts the server;
  `@WEB SERVER START` checks `OperatingMode::MAINTENANCE` inside its own branch; `HttpTransport`
  never calls `esp_restart()`; the OTA secret is referenced only at its one call site. Every new
  check was manually mutation-tested before being trusted — one draft (the MAINTENANCE-gate check)
  was itself caught matching the wrong branch and rewritten before being trusted.
- `MATDOG_OTA_INGEST_ENABLED` remains `0` by default, unchanged — the transport's existence does
  not make ingest reachable; starting the Web server checks `OtaManager::ingestEnabled()` and
  returns `403` if it is off.
- Build cost vs the previous frozen candidate (`c8906378`): `USB_ONLY` flash 981,856 B → 1,024,288 B
  (31% → 32%, +42,432 B — the `esp_http_server`/mbedTLS-linked HMAC path and the FreeRTOS semaphore
  API), static RAM 53,356 B → 56,660 B (16% → 17%, +3,304 B).

Full record:
[`09_Logs/Development_Log/2026-09-25_I7_I8_NETWORK_TRANSPORT_IMPLEMENTATION.md`](../../09_Logs/Development_Log/2026-09-25_I7_I8_NETWORK_TRANSPORT_IMPLEMENTATION.md).

## Unreleased — F0 re-run against the integrated candidate — 2026-09-25

Documentation only; **no flash attempted or proposed**. `FINAL_FLASH_ELIGIBLE=DEFERRED_UNPOWERED`
— unchanged, the ESP32 was never enumerated this session. `SOFTWARE_FREEZE_GATE`,
`ARTIFACT_PROVENANCE_GATE` and `FAIL_CLOSED_GATE` all PASS against the MATDOG NEXTGEN INTEGRATED
HARDWARE VALIDATION CANDIDATE. Full record:
[`09_Logs/Development_Log/2026-09-25_F0_RERUN_CANDIDATE.md`](../../09_Logs/Development_Log/2026-09-25_F0_RERUN_CANDIDATE.md).

## Unreleased — MATDOG NEXTGEN INTEGRATED HARDWARE VALIDATION CANDIDATE — 2026-09-25

Documentation only; **no code change**. Full integrated software freeze superseding the earlier I9
freeze, run from this exact clean commit after I6 (HostLink), I7 (reconsidered), I4/I5 (Controller
wiring) and I8 (reconsidered):

- C++ host suites: **14 suites, 5726 checks, 0 failures**.
- Static audit: **PASS, 89 files, 0 findings**.
- Python suites: **370 collected, 366 passed, 4 known/justified failures** (identical result to
  I9 — same pre-existing root cause, no Python source changed).
- `USB_ONLY` 981,856 B / `ROBOT_POWERED` 982,432 B (SHA256
  `94ae5c4a5152d914520db579d0282f0df5b540a56b90e9a772e67954e244b6b0`), both clean from commit
  `c8906378df04468d886d6c1d064f67f74a16042b`.
- Fail-closed re-verified, now covering the I4/I5/I6 additions: `ActuatorRuntime`/
  `CalibrationExecutionEngine` are Controller-owned but wired with a `nullptr` backend and no
  geometry/limit/transform ever admitted; no command path reaches `plan`/`commit`/`execute`/
  `abort` (audit-enforced, mutation-verified).

This artifact is named **MATDOG NEXTGEN INTEGRATED HARDWARE VALIDATION CANDIDATE** per the
operator's instruction — the single build the later physical campaign will validate. Full record:
[`09_Logs/Development_Log/2026-09-25_INTEGRATED_FREEZE_CANDIDATE.md`](../../09_Logs/Development_Log/2026-09-25_INTEGRATED_FREEZE_CANDIDATE.md).

## Unreleased — I8 reconsidered, no server code added — 2026-09-25

Documentation only; **no code change**. Reconsidered the read-only Web foundation now that I6 is
substantially implemented. Split UI-0 into a data/schema half (already done — `ControllerService`
IS the typed semantic/telemetry layer a future HTTP handler would serve) and a server half
(`WebServer`/`esp_http_server`/`esp_https_server`, all requiring `<WiFi.h>` and, for two of the
three, an additional FreeRTOS task). Declined to add the server half: its central safety property
("bounded memory/latency") is not testable without live Wi-Fi association, and unlike
`MATDOG_OTA_INGEST_ENABLED` (which gates an already-reviewed state machine), there is no existing
offline-tested decision core to gate an HTTP stack behind — it would be new, unreviewed surface
area. `ServiceReadiness`'s `WEB_READ_ONLY_DASHBOARD` capability already reports the
"disabled/not qualified until Wi-Fi hardware validation" state as data. Full reasoning:
[`09_Logs/Development_Log/2026-09-25_I8_RECONSIDERED.md`](../../09_Logs/Development_Log/2026-09-25_I8_RECONSIDERED.md).

## Unreleased — I4/I5 Controller wiring — 2026-09-25

**Implemented, compiled and offline-tested. NOT flashed. NOT hardware-tested. Fail-closed by
construction and by audit.**

- **`Controller` now owns real `SafeActuatorPolicy`/`ActuatorRuntime`/`CalibrationExecutionEngine`
  instances** as status/lifecycle infrastructure — previously none of the three were wired into
  `Controller` at all. `actuator_runtime_` is given `nullptr` as its backend (every `ACCEPT`
  resolves to `NO_BACKEND` regardless of anything else); no geometry/limit/transform is ever
  admitted from `Controller`; no command path calls `plan()`/`commit()`/`execute()`/`abort()`.
- **New `@ACTUATOR STATUS`** (read-only): policy epoch, outstanding-transaction flag, last
  decision, counters, limits/transforms-admitted counts, geometry-bound flag.
- **New static-audit check** `check_actuator_infrastructure_wired_fail_closed()` enforces the
  three fail-closed choices above structurally. **A manual mutation check caught a real bug**: the
  first version of the "no plan/commit/execute/abort call" rule matched only `.method(` and missed
  every actual call site, which uses `->method(` (`modules_.actuator_policy` is a pointer) — fixed
  to a regex matching both syntaxes, re-verified via the same injected-then-reverted mutation.
  The I4/I5 boundary checks were extended to allow `Controller.h`/`Controller.cpp` by exact
  filename (not by directory), so `CommandRouter.cpp`/`ControllerService.h` remain excluded.
- **Cost:** `USB_ONLY` flash 979,111 B -> 981,727 B (+2,616 B — no longer dead-code-eliminated,
  since `Controller` now genuinely calls into it), RAM +872 B; `ROBOT_POWERED` 979,655 B ->
  982,299 B (+2,644 B). Full record:
  [`09_Logs/Development_Log/2026-09-25_I4_I5_CONTROLLER_WIRING.md`](../../09_Logs/Development_Log/2026-09-25_I4_I5_CONTROLLER_WIRING.md).

## Unreleased — I7 reconsidered, scope unchanged — 2026-09-25

Documentation only; **no code change**. Reconsidered building the USB CDC OTA ingest transport
under the objective-change instruction (real ingest may stay disabled by default in the frozen
candidate either way). Found a concrete blocker: `CommandRouter::kLineBufSize = 96` bytes means a
usable ingest transport needs a genuine second Serial I/O mode (suspending line parsing for
length-prefixed binary reads), not a thin adapter over the existing `OtaManager` API — real,
unreviewed I/O architecture whose interaction with the G3.1 non-blocking USB CDC guarantee was not
assessed this session. Building it would not change the frozen candidate's reachable behavior
(ingest stays compiled out either way) while carrying real risk. Re-confirmed `OtaPolicy::reset()`
already provides the transport-independent retry primitive. Full reasoning:
[`09_Logs/Development_Log/2026-09-25_I7_RECONSIDERED.md`](../../09_Logs/Development_Log/2026-09-25_I7_RECONSIDERED.md).

## Unreleased — I6 HostLink implementation (candidate objective change) — 2026-09-25

**Implemented, compiled and offline-tested. NOT flashed. NOT hardware-tested.** Supersedes the
earlier audit-only I6 gate, per the operator's instruction to produce one maximally integrated
hardware-validation candidate: sequencing gates activation/validation, not offline preparation of
fail-closed software.

- **New `src/core/ServiceReadiness.{h,cpp}`** — pure readiness classifier. 8 named capabilities x
  hardware-validation flags -> `READY`/`TO_TEST`/`BLOCKED`. 31 offline checks.
- **New `src/core/ControllerService.h`** — transport-neutral telemetry layer, scope bounded to
  passive status reads. ~30 accessors, each a one-line forward of a struct its module already
  computed — zero duplicated logic. Action/write commands stay `CommandRouter`-direct.
- **`CommandRouter` refactored** (not duplicated): every read-only `print*` method now routes
  through `ControllerService`. New `@HOSTLINK READINESS` command surfaces the classifier.
- **New static-audit check** `check_service_readiness_is_host_linkable()`. The pre-existing
  DALY-KEY-probe scope check was extended to allow `ControllerService.h` as a reviewed consumer
  (same reasoning already applied to `CommandRouter`); the full DALY mutation suite (52/52) was
  re-verified green afterward.
- **Cost:** `USB_ONLY` flash 978,336 B -> 979,111 B (+775 B), RAM +64 B; `ROBOT_POWERED`
  978,896 B -> 979,655 B (+759 B). Offline baseline now 14 host suites / 5726 checks. Full record:
  [`09_Logs/Development_Log/2026-09-25_I6_HOSTLINK_IMPLEMENTATION.md`](../../09_Logs/Development_Log/2026-09-25_I6_HOSTLINK_IMPLEMENTATION.md).

## Unreleased — F0 final flash readiness — 2026-09-25

Documentation only; **no flash attempted or proposed**.

- `SOFTWARE_FREEZE_GATE`, `ARTIFACT_PROVENANCE_GATE` and `FAIL_CLOSED_GATE` all **PASS**.
  `POWER_ISOLATION_GATE=UNPROVEN` and `FLASH_RECOVERY_GATE=DEFERRED_UNPOWERED` — unchanged since
  I0, the ESP32 was never enumerated this session (`USB_STATE=ESP32_NOT_ENUMERATED`).
- `FINAL_FLASH_ELIGIBLE=DEFERRED_UNPOWERED` per the handoff's explicit rule. No authorization
  question was asked (Section 19 applies only when `FINAL_FLASH_ELIGIBLE=PASS`).
- Recorded the exact future flash procedure (prove power isolation → fresh full-flash read-back
  under proven power → re-run F0 → Section-19 report → explicit YES/NO → application-only flash via
  `flash_app_only.sh`) so nothing has to be re-derived once the operator is physically present.
  Full record:
  [`09_Logs/Development_Log/2026-09-25_F0_FINAL_FLASH_READINESS.md`](../../09_Logs/Development_Log/2026-09-25_F0_FINAL_FLASH_READINESS.md).

## Unreleased — I9 integrated software freeze — 2026-09-25

Documentation only; **no code change**. Full offline validation matrix run from a clean tree:

- C++ Controller host suites: **13 suites, 5695 checks, 0 failures**.
- Static safety audit (mutation guards, OTA partition tests, build-manifest tests included):
  **PASS, 85 files, 0 findings**.
- Python kinematics/calibration suites (`06_Software/Matdog_Core`): **370 collected, 366 passed, 4
  known/justified failures** — all four are the pre-existing, already-documented live-FK
  `calibration_status` YAML/loader enum mismatch (I1, `CALIBRATION_SOURCE_PRECEDENCE.md` §9 item
  1), not a regression and explicitly not fixed per the V3 handoff's own instruction.
- Both hardware profiles compiled clean from commit `cc0940b0f62f242f0ab66c09ea24f7cb8ed2aa08`:
  `USB_ONLY` 978,336 B / `ROBOT_POWERED` 978,896 B (SHA256
  `a292b2166d5381f1a8f75c494f79753e8aae4a23ee875c42325fe10ecb35203b`). Default `USB_ONLY` artifact
  restored last.
- Fail-closed re-verified directly against source: `hardware_motion_authorized=0`,
  `USB_ONLY` source default, OTA ingest `=0` — all audit-enforced. Neither of this session's two
  new adapters (I4 `ActuatorRuntime`, I5 `CalibrationExecutionEngine`) is referenced by
  `Controller`/`CommandRouter`; both are proven dead-code-eliminated from both compiled profiles.
- Full record, final artifact provenance and classification matrix:
  [`09_Logs/Development_Log/2026-09-25_I9_INTEGRATED_SOFTWARE_FREEZE.md`](../../09_Logs/Development_Log/2026-09-25_I9_INTEGRATED_SOFTWARE_FREEZE.md).

## Unreleased — I8 deferred — 2026-09-25

No code or status change. I8 (read-only Web foundation) requires I6 semantics "stable" (I6 was
audit-only, `HostLink` remains `TO_DESIGN`), Wi-Fi runtime `PASS` (hardware-untested, out of scope
this session) and a chosen web transport (deliberately left undecided in I7). Deferred rather than
attempted with a workaround. Full reasoning:
[`09_Logs/Development_Log/2026-09-25_I8_WEB_FOUNDATION_DEFERRED.md`](../../09_Logs/Development_Log/2026-09-25_I8_WEB_FOUNDATION_DEFERRED.md).

## Unreleased — I7 Wi-Fi/OTA audit — 2026-09-25

Documentation only; **no code change**.

- Checked V3 handoff's eleven Wi-Fi/OTA sub-items against the existing implementation: nine
  (authorization, session semantics, manifest identity, hash validation, pending-reboot,
  recovery invariant, bounded memory, concurrency, status reporting) were already complete.
  Authenticated transport remains deliberately unimplemented — the Controller README already
  evaluates five transport options with a "not yet implemented" recommendation, and building even
  the recommended first step (USB CDC ingest) means writing the first reachable firmware-write
  code path in this codebase, which is a decision-grade commitment, not routine offline
  advancement. `failure/retry` semantics are inseparable from that undecided transport. Full
  reasoning:
  [`09_Logs/Development_Log/2026-09-25_I7_WIFI_OTA_AUDIT.md`](../../09_Logs/Development_Log/2026-09-25_I7_WIFI_OTA_AUDIT.md).

## Unreleased — I6 HostLink audit — 2026-09-25

Documentation only; **no code change**.

- Audited `CommandRouter`'s transport coupling: most read-only state is already
  transport-independent (structured snapshots per module, the G2 pattern); dispatch and
  presentation for all 25 `@COMMAND`s remain embedded in the 792-line USB CDC adapter itself.
  Recorded a design sketch for a future semantic layer, not implemented.
- Scoped this gate to audit-only rather than implementation: `DEVELOPMENT_GATES.md`'s own rule 6
  forbids pulling the HostLink gate forward of its unmet prerequisites (Service/Provisioning/QC,
  formal recalibration), and its `PASS CRITERIA` (a second transport consuming the same semantics)
  is unverifiable without a second transport, which is itself gated behind Wi-Fi hardware
  validation this phase does not authorize. Full reasoning:
  [`09_Logs/Development_Log/2026-09-25_I6_HOSTLINK_AUDIT.md`](../../09_Logs/Development_Log/2026-09-25_I6_HOSTLINK_AUDIT.md).

## Unreleased — I5 Calibration Execution Architecture — 2026-09-25

**Implemented, compiled and offline-tested. NOT flashed. NOT hardware-tested. No production
backend exists. Persistence/promotion remains TO_DESIGN.**

- **Corrected stale documentation**: `DEVELOPMENT_GATES.md` previously said the calibration
  execution engine meant "the 18 recovered phases" — conflating the LF V25 historical oracle with
  the production architecture, which V3 handoff §15.11 forbids. Fixed.
- **New `src/calibration/CalibrationExecutionEngine.{h,cpp}`** — a generic, intent-based
  Calibration Execution boundary (`CalibrationIntent`: `CONTACT_PROBE`/`AUXILIARY_MOVE`/
  `DIRECTION_VERIFY`/`RESTORE`/`ABORT`), routing the three executable intents through the
  unmodified `SafeActuatorPolicy`/`ActuatorRuntime`. `RESTORE` and `ABORT` are categorically
  non-executing — neither ever reaches a backend call, by construction, which is what makes
  "authority loss → zero restore motion" true without a special-cased guard. Owns no session
  state, no persistence, no geometry profile, and never references `CalibrationPhase` — the LF V25
  18-phase sequence stays a historical oracle, exercised only by
  `test_calibration_domain.cpp`'s existing replay.
- **New static-audit check** `check_calibration_execution_engine_boundaries()`: fails the build if
  the engine stops being host-linkable, references the 18-phase sequence, names a torque-removal
  primitive, or is referenced anywhere outside `src/calibration/`/the offline suite.
  `check_actuator_runtime_boundaries()` (I4) was extended to allow this new legitimate consumer.
  Confirmed independently: both hardware profiles compile to byte-identical flash sizes with and
  without the engine present.
- **New offline suite** `test_calibration_execution_engine.cpp`: 72 checks, 0 failures, covering
  all ten operator-specified adversarial cases (authority loss → no restore motion, stale
  generation, diagnostic-endpoint refusal, wrong geometry provenance, replay-origin refusal, no
  accepted transform → no raw target, CALIBRATION-only eligibility, MOTION exclusion, abort/
  restore/SAFE_OFF distinctness, unknown-intent fail-closed). Offline baseline is now 13 host
  suites / 5695 checks (previously 12 / 5623). Full record:
  [`09_Logs/Development_Log/2026-09-25_I5_CALIBRATION_EXECUTION_ENGINE.md`](../../09_Logs/Development_Log/2026-09-25_I5_CALIBRATION_EXECUTION_ENGINE.md).
- **Cost:** `USB_ONLY` and `ROBOT_POWERED` flash/RAM unchanged (978,195 B / 978,751 B).

## Unreleased — I4 Safe Actuator runtime boundary — 2026-09-25

**Implemented, compiled and offline-tested. NOT flashed. NOT hardware-tested. No production
backend exists.**

- **New `src/actuator/ActuatorRuntime.{h,cpp}`** — the runtime adapter `SAFE_ACTUATOR_LAYER.md`
  §7 marks `TO_IMPLEMENT`: an abstract `ActuatorBackend` interface (`enableTorque`/
  `writeGoalPosition`, unsigned tick domain) and `ActuatorRuntime`, which calls
  `SafeActuatorPolicy::commit()` once and issues at most one backend call, only on `ACCEPT`.
  `ActuatorWritePolicy.*` itself is untouched.
- **`ServoBus` still exposes exactly one write, `safeOff()`** — no `EnableTorque(id, 1)`/
  `GoalPosition` primitive exists, so no production `ActuatorBackend` was created. The adapter is
  exercised only offline against a fake backend.
- **The three geometry-authorised operations** (`CALIBRATION_CONTACT_PROBE`/`DIRECTION_VERIFY`/
  `CALIBRATION_AUXILIARY_MOVE`) have no raw-tick target yet — that conversion needs an accepted
  q0/direction transform from a real execution engine (deferred to I5) — and always resolve to
  `ExecuteResult::NO_RAW_TARGET`, never a guessed conversion.
- **New static-audit check** `check_actuator_runtime_boundaries()`: fails the build if the adapter
  stops being host-linkable, or if `ActuatorRuntime` is referenced anywhere outside
  `src/actuator/`/the offline suite. Confirmed independently: both hardware profiles compile to
  byte-identical flash sizes with and without the adapter present — the linker dead-code-eliminates
  it entirely since nothing references it.
- **New offline suite** `test_actuator_runtime.cpp`: 46 checks, 0 failures, including an explicit
  proof that a rejected commit never reaches the backend. Offline baseline is now 12 host suites /
  5623 checks (previously 11 / 5577). Full record:
  [`09_Logs/Development_Log/2026-09-25_I4_ACTUATOR_RUNTIME.md`](../../09_Logs/Development_Log/2026-09-25_I4_ACTUATOR_RUNTIME.md).
- **Cost:** `USB_ONLY` and `ROBOT_POWERED` flash/RAM unchanged (978,195 B / 978,751 B) — the
  adapter contributes zero bytes to either compiled image.

## Unreleased — I3 SOURCE_SIGNATURE — 2026-09-25

- **New `@SYSTEM SOURCE_SIGNATURE`** read-only command: reports `build::kBuildId`, firmware name/
  version, active profile/board, the OTA manager's running-image build id/state/reset reason, and
  the ESP-IDF running partition. All facts were already computed elsewhere (boot banner, OTA
  first-boot self-check) — no new hardware read, no new bus traffic. Closes the `SOURCE_SIGNATURE`
  item of G4's documented gap list. `SYSTEM_SELF_TEST`, `PROFILE_AUDIT` and a consolidated servo
  health summary remain open design questions, deliberately not guessed — see
  [`09_Logs/Development_Log/2026-09-25_I3_SOURCE_SIGNATURE.md`](../../09_Logs/Development_Log/2026-09-25_I3_SOURCE_SIGNATURE.md).
- **Cost:** `USB_ONLY` flash 977,747 B -> 978,195 B (+448 B); `ROBOT_POWERED` 978,299 B -> 978,751 B
  (+452 B). RAM unchanged.

## Unreleased — I2 LED Status Manager — 2026-09-25

**Implemented, compiled and offline-tested. NOT flashed. NOT hardware-tested.**

- **New `src/status/LedStatusPolicy.{h,cpp}`** — pure LED presentation decision core, host-linkable
  like `network::WifiPolicy`/`update::OtaPolicy` (no `<Arduino.h>`, no `LedRing` dependency).
  Deterministic priority: `FAULT` > `FIRMWARE_UPDATE_IN_PROGRESS` > `CALIBRATION_IN_PROGRESS` >
  `DEGRADED` > `WIFI_CONNECTING` > `BOOTING` > `READY`. Solid effects for fault/degraded/booting/
  ready; a pure integer triangle-wave breathing effect for update/calibration/wifi-connecting.
- **New `src/status/LedStatusManager.{h,cpp}`** — the single periodic owner of `LedRing`
  presentation, wired into `Controller::update()` last, after every input it reads has refreshed
  for the tick. Steps aside while the existing `@LED TEST` diagnostic chase is running; reuses
  `LedRing` completely unchanged, including its `USB_ONLY` anti-back-power guarantee.
- **Battery/charging states deliberately NOT implemented**: no reviewed SOC/taper threshold policy
  exists yet (`MATDOG_POWER_STATES_AND_CHARGING.md` §14). Full architecture table and rationale in
  [`09_Logs/Development_Log/2026-09-25_I2_LED_STATUS_MANAGER.md`](../../09_Logs/Development_Log/2026-09-25_I2_LED_STATUS_MANAGER.md).
- **New static-audit check** `check_led_status_boundaries()`: fails the build if the decision core
  stops being host-linkable, or if any translation unit other than `LedStatusManager.cpp` calls
  `LedRing::setSolid()`.
- **New offline suite** `test_led_status_policy.cpp`: 198 checks, 0 failures. Offline baseline is
  now 11 host suites / 5577 checks (previously 10 / 5379).
- **`@LED STATUS`** now also reports `presentation=<state>`, read-only.
- **Cost:** `USB_ONLY` flash 976,991 B -> 977,747 B (+756 B), RAM 52,404 B -> 52,420 B (+16 B);
  `ROBOT_POWERED` flash 977,471 B -> 978,299 B (+828 B).

## Unreleased — NextGen software integration I0/I1 — 2026-09-25

Documentation and repository-topology only; **no firmware change**.

- **I0:** created the single active integration branch/worktree
  `feat/controller-nextgen-integration-v1` from exact H0 HEAD `b95ea31641609fbc29c5d67dd1deb776d59c2504`
  (`feat/h0-current-leg-preflight-v1`), no content commit, pushed with upstream set. `main`,
  `feat/h0-current-leg-preflight-v1` and every other frozen branch/worktree left untouched.
- **I1:** repository-truth reconciliation. Fixed the root `README.md` snapshot banner (stale at
  2026-09-15, now 2026-09-25). Added the H0 `@SERVO PREFLIGHT` capability, previously undocumented
  in `ROADMAP.md` and `DEVELOPMENT_GATES.md`, to both. Carried the six legacy open items from the
  historical `REPOSITORY_VERIFICATION_INDEX.md` (2026-08-11) snapshot forward into
  `CALIBRATION_SOURCE_PRECEDENCE.md` §9 as explicit, unresolved, owned items. Full record:
  [`09_Logs/Development_Log/2026-09-25_I1_REPOSITORY_TRUTH_RECONCILIATION.md`](../../09_Logs/Development_Log/2026-09-25_I1_REPOSITORY_TRUTH_RECONCILIATION.md).

## Unreleased — post-rewire power validation & external USB service port closeout — 2026-09-24

Documentation and evidence only; **no firmware change**. No firmware commit since `6322563`
(2026-09-19) touched source (`4604e36`/`efba2dc`/`19fe837` are test-only or docs-only), so the
robot exercised in this session ran the already-installed powered firmware from the earlier live
DALY work. Full evidence:
[`09_Logs/Development_Log/2026-09-24_MATDOG_POWER_CHARGING_USB_VALIDATION_CLOSEOUT.md`](../../09_Logs/Development_Log/2026-09-24_MATDOG_POWER_CHARGING_USB_VALIDATION_CLOSEOUT.md).

- **Hardware `B-`/`P-` bypass corrected and verified:** TECNOIOT `VIN-` now returns to DALY `P-`
  instead of raw battery `B-`. Post-rewire power gate A–E passed live: with no charger and no USB
  present, physical KEY OFF now removes the entire protected robot domain (servo rail, TECNOIOT
  output and PAD+→PAD- all measured 0 V), and the powered no-motion regression (BNO085/DALY/servo
  census/`SAFE_OFF`) still holds.
- **Manual charging common-port behaviour discovered and documented:** a charger connected across
  `B+`/`P-` backfeeds that bus independent of KEY/Discharge-MOS state — KEY OFF while a charger is
  connected does **not** de-energize the robot. The previous "manual charging with KEY OFF → robot
  domain OFF" description was never live-verified and is now corrected; see
  `04_Electronics/MATDOG_POWER_STATES_AND_CHARGING.md` § 8 for the renamed `MANUAL_CHARGE_KEY_OFF`
  state and its accurate semantics.
- **External USB service/programming port (GPIO19 D-, GPIO20 D+, GND, no host VBUS) validated:**
  native enumeration, bidirectional CDC, and the `esptool` reset/flash-identification path all
  confirmed through the external connector alone, with correct re-enumeration after reset. The port
  cannot power the ESP32 on its own.
- Remaining open: BMS KEY-configuration persistence across a true DALY power cycle (**TO_TEST**);
  autonomous dock/contact hardware, reverse-polarity protection, unattended charge
  acceptance/termination, future Jetson charging (**FUTURE**); charging LED-ring progress
  indication (**FUTURE / TO_DESIGN, NOT IMPLEMENTED** — no firmware for it exists).

## Unreleased — calibration foundation + LF V25 oracle recovery — 2026-09-21

**Implemented, compiled and offline-tested. NOT flashed. NOT hardware-tested.**
**No write path was added**: the firmware's only actuator write is still `EnableTorque(id, 0)`
inside `safeOff()`. The installed robot's calibration remains
`CALIBRATION_RESET_PENDING_FULL_RECALIBRATION` and hardware motion remains **BLOCKED**.

- **C0 evidence audit recorded** in `CALIBRATION_SOURCE_PRECEDENCE.md`: source precedence,
  current calibration truth, what LF V25 actually proved, the three evidence vocabularies, four
  discrepancies, the Generic V25 component assessment and the EEPROM boundary.
- **New `src/calibration/`** — a pure, host-linkable domain model recovered from the archive
  (no Arduino runtime, no ServoBus, no Wi-Fi, no OTA) and a `CalibrationManager` session
  foundation over the real `ActuatorAuthority`, creating no second lock.
- **Confirmed from the archive, not assumed:** 24 contact profiles (4x3x2, and the archive's own
  test asserts it), 58 sequence steps, six LF contacts, 18 execution phases.
- **Three findings encoded as types.** q0 cannot default to the raw servo centre - 2048 is three
  different quantities and LF V25's measured q0 was 2067/2040/2074. There is no "direction
  witness" in the archive; `direction` is a static spec constant, and the witness that exists is
  the CONTACT witness. Evidence is keyed by physical unit, never bus id, because unit M11 is
  NECK_PITCH today while bus id 11 still means "LF lower".
- **The 24-tick witness band is historical and LF-only**, kept in the fixture rather than
  promoted to a universal domain constant - the evidence file forbids mirroring LF onto RF/RH/LH.
- **"H1" avoided in new code.** The repository uses it for both the Full-Leg population gate and
  the Controller's own boot test; new code says leg population gate. It evaluates evidence and
  never scans - there is one bus discovery path and a second census is forbidden.
- **LF V25 replayed offline and MATCHED**, including the one documented failure. Every replayed
  record carries `HISTORICAL_REPLAY`, which `mayPromote()` refuses.
- **Surface:** `@CALIBRATION STATUS`, read-only, leading with the stale/blocked verdict, plus a
  `calibration` line on the boot banner. No START/RUN/MOVE command was added.
- **Audit gains twelve calibration guards**, all twelve mutation-verified.
- **Cost:** flash 970,127 B -> 973,463 B (+3,336 B, 30% of the 3 MB slot); static RAM 51,740 B ->
  51,812 B (+72 B).

## Unreleased — ActuatorAuthority + OTA-B authorization — 2026-09-21

**Implemented, compiled and offline-tested. NOT flashed. NOT hardware-tested.**
**No new write path was added** — the firmware's only actuator write is still
`EnableTorque(id, 0)` inside `safeOff()`, nothing can acquire an owner yet, and there is
deliberately no command that does.

- **New `src/core/ActuatorAuthority.*`** — the single central arbiter of actuator write
  authority. Pure and host-linkable: no Arduino runtime, no `ServoBus`, no `Serial`. Exactly one
  instance exists, owned by `Controller`, reset to `NONE` at boot; no component caches its value.
  Both are audit-enforced.
- **Orthogonal to `OperatingMode`, and enforced as such.** `MAINTENANCE` hosts the service owners
  but not `MOTION`; `RUN` hosts `MOTION` and nothing else. A mode change that strands an owner
  clears it instead of leaving a suspended authority — a no-op today, added so the first real
  owner does not have to remember it.
- **`SAFE_OFF` is outside arbitration, structurally.** `ServoBus` has no reference to the arbiter
  and the arbiter has none to `ServoBus`, so `safeOff()` cannot consult an authority even if a
  later edit wanted it to. The audit fails the build if `ServoBus` names one, or if the
  `@SERVO SAFE_OFF` branch gains an authority or mode condition.
- **Read-only diagnostics deliberately take no lock.** `@SERVO SCAN`/`CENSUS`/`READ` are
  `Ping`/`readByte`/`readWord` and are `MAINTENANCE`-gated because they **block**. The arbiter
  prevents write conflicts; it does not serialize reads.
- **Two semantics chosen deliberately.** A same-owner re-request returns `ALREADY_OWNED` and
  issues **no** second lease — a second valid lease would let two holders each believe they own it
  and either release it out from under the other. And leases carry a generation, which catches the
  case owner-matching cannot: the *same* owner across two sessions, where a late callback from the
  first would otherwise clear the second.
- **OTA-B authorization implemented; the OTA-A placeholder removed, not kept.** `OtaStageAGate`
  and `PERMITTED_OTA_A_NO_AUTHORITY_MODEL_YET` are gone and the audit fails the build if either
  name reappears. `src/update/OtaAuthorityGate.*` is backed by the real arbiter.
- **OTA is not an actuator owner** and no OTA entry was added to the enum — audit-enforced. It
  takes an **exclusivity inhibit** instead, because it requires that nobody is using the actuators
  rather than competing for them.
- **The TOCTOU analysis, and what it did NOT require.** `if (authority == NONE) { start OTA }` is
  genuinely insufficient — not because of threading (MATDOG's Controller is single-threaded, so a
  check-then-act inside one call is already atomic) but because of **duration**: an update spans
  thousands of loop passes. The fix is a hold, not a query: `requestInhibit()` performs the check
  and takes the hold in one arbiter call. **No `SystemActivity` layer was needed and none was
  built.** The hold is released on every failure, abort and reset, and kept after a successful
  commit until the reboot.
- **Surface:** `@AUTHORITY STATUS` (read-only), `authority=` on the existing `@STATUS` SYSTEM line
  (~24 B, keeping the worst single-pass burst at ~2782 B against the 3072 B TX ring),
  `actuator_authority` on the boot banner, and `@MODE MAINTENANCE|RUN` now telling the arbiter.
- **`core/OperatingMode` became host-linkable** (`<stdint.h>` instead of `<Arduino.h>`); it only
  ever needed `uint8_t`, and the arbiter consults it while staying testable off the device.
- **Offline suites:** 751 new checks for the arbiter, including the exhaustive 20-pair conflict
  matrix with each challenger tried in its own legal mode, corrupted-enum fail-closed, stale-lease
  refusal, force-clear under every reason, and the full inhibit lifecycle. The OTA suite grew
  468 → 561 and now links the **real** gate and the **real** arbiter.
- **Audit gains eleven guards**, all eleven mutation-verified.
- **Cost:** flash 967,915 B → 970,127 B (+2,212 B, 30% of the 3 MB slot); static RAM 51,676 B →
  51,740 B (+64 B).

## Unreleased — OTA-A update core — 2026-09-21

**Implemented, compiled and offline-tested. NOT flashed. NOT hardware-tested** — no device has
received an OTA image, no otadata has been written, no rollback has been observed. OTA-A is the
update **core only**: no transport, no authentication, and byte ingest compiled out by default.

- **New `src/update/` module**, split the way `network/` already is: `OtaPolicy.*` (pure update
  state machine), `OtaBootGuard.*` (first-boot rollback lifecycle), `Sha256.*` (image identity) —
  all Arduino-free and ESP-IDF-free — behind an `OtaBackend` interface implemented by
  `OtaEspBackend.*`, the only translation unit in the firmware that calls `esp_ota_*`.
- **The inactive-slot rule is structural, not documentary.** `target != running`,
  `subtype ∈ ota_0..ota_15` and `image_size ≤ target.size` are explicit refusals rather than
  inferences from a backend error; `OtaEspBackend::setBootPartition()` re-reads
  `esp_ota_get_running_partition()` and refuses independently; and `commitBootTarget()` is the one
  method that moves the boot target, with one call site, reachable from exactly one state.
  `flash_app_only.sh` was audited for reusable logic and deliberately **not** adopted as the OTA
  writer — it writes the **active** slot over USB and is a different guarantee.
- **Five kinds of verification kept distinct** — transport integrity, image validity
  (`esp_ota_end`), cryptographic hash identity (our SHA-256), firmware/build identity
  (`build::kBuildId`), bootloader validity (otadata). Only the third distinguishes "a valid image"
  from "the expected image", and the host suite proves it with a mismatched image of identical
  length.
- **`esp_app_desc_t` rejected as firmware identity**, on evidence: parsing the real binary shows
  `version='ee57070'`, `project_name='arduino-lib-builder'`, `date='Jul 20 2026'` — the core's
  identity, not MATDOG's. The existing scheme (`build::kBuildId` + the manifest's
  `APPLICATION_SHA256`/`APPLICATION_SIZE`) is reused; no second version scheme was invented.
- **First-boot confirmation is earned, not granted.** With `CONFIG_BOOTLOADER_APP_ROLLBACK_ENABLE=y`
  in the real build, never confirming is the safe default — the bootloader aborts a
  `PENDING_VERIFY` image on the next boot by itself. `esp_ota_mark_app_valid_cancel_rollback()` is
  called only after Controller init completed, CommandRouter is bound, identity is readable, the
  boot did not follow PANIC/WDT/BROWNOUT, and the image survived ≥ 15 s **and** ≥ 2000 loop ticks.
  The audit fails the build if `Controller::begin()` ever confirms an image.
- **Refusal does not reboot.** Declining to confirm is already sufficient; rebooting a robot is not
  OTA-A's decision. Explicit operator rollback is **OTA-B**.
- **OTA-B boundary without a mini-authority.** `OtaAuthorizationGate` fails closed with no gate
  installed; OTA-A permission is a named object (`OtaStageAGate`) whose verdict is literally
  `PERMITTED_OTA_A_NO_AUTHORITY_MODEL_YET`.
- **Security stated as a compile-time fact.** `MATDOG_OTA_INGEST_ENABLED` defaults to `0` and the
  audit fails the build if the source default changes — same shape as the `USB_ONLY` profile gate —
  so an unauthenticated firmware writer cannot reach a production image.
- **Erase strategy chosen for loop responsiveness.** `esp_ota_begin()` uses
  `OTA_WITH_SEQUENTIAL_WRITES`: an explicit size erases ~1 MB up front, seconds of blocking. The
  size bound stays an explicit policy check instead of being delegated to the erase argument.
- **Offline suite:** 468 checks against the real state machine with a fake backend — every target,
  metadata, stream and verification failure; the ordering property that the boot target never moves
  from any state but `IDENTITY_VERIFIED`; replay, idempotent abort and state-machine reset; and the
  full rollback lifecycle. SHA-256 checked against FIPS 180-4 vectors, at eight chunk sizes, and
  byte-for-byte against `sha256sum` on the real 959 KB binary.
- **Audit gains thirteen OTA guards**, each mutation-verified. One initially escaped because the
  mutation hit the comment documenting the erase strategy rather than the call; re-run against the
  real call site, it fires.
- **Cost:** flash 959,043 B → 967,915 B (+8,872 B, 30% of the 3 MB slot); static RAM 50,868 B →
  51,676 B (+808 B). No image is ever held in RAM.
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

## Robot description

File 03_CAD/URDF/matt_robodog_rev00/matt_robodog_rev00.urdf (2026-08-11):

<?xml version='1.0' encoding='utf-8'?>
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
<robot name="matt_robodog_rev00">
  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
  <link name="base_link">
    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
    <inertial>
      <origin xyz="0.00584 -0.00065 0.02773" rpy="0 0 0" />
      <mass value="1.282000" />
      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
    </inertial>
    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
  </link>
  <link name="lf_hip_link">
    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
    <inertial>
      <origin xyz="0.00366 0.02982 0.00694" rpy="0 0 0" />
      <mass value="0.050000" />
      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
    </inertial>
    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
  </link>
  <link name="lf_upper_leg_link">
    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
    <inertial>
      <origin xyz="0.00108 0.00015 -0.04503" rpy="0 0 0" />
      <mass value="0.172500" />
      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
    </inertial>
    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
  </link>
  <link name="lf_lower_leg_link">
    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
    <inertial>
      <origin xyz="0.03075 -0.00118 -0.01958" rpy="0 0 0" />
      <mass value="0.059500" />
      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
    </inertial>
    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
  </link>
  <link name="lf_foot_link">
    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
    <inertial>
      <origin xyz="-0.00052 0 0.01548" rpy="0 0 0" />
      <mass value="0.017500" />
      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
    </inertial>
    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
  </link>
  <link name="rf_hip_link">
    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
    <inertial>
      <origin xyz="0.00366 -0.02982 0.00694" rpy="0 0 0" />
      <mass value="0.050000" />
      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
    </inertial>
    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
  </link>
  <link name="rf_upper_leg_link">
    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
    <inertial>
      <origin xyz="0.00108 -0.00015 -0.04503" rpy="0 0 0" />
      <mass value="0.172500" />
      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
    </inertial>
    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
  </link>
  <link name="rf_lower_leg_link">
    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
    <inertial>
      <origin xyz="0.03075 0.00118 -0.01958" rpy="0 0 0" />
      <mass value="0.059500" />
      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
    </inertial>
    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
  </link>
  <link name="rf_foot_link">
    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
    <inertial>
      <origin xyz="-0.00052 0 0.01548" rpy="0 0 0" />
      <mass value="0.017500" />
      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
    </inertial>
    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
  </link>
  <link name="rh_hip_link">
    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
    <inertial>
      <origin xyz="0.00366 -0.02982 0.00694" rpy="0 0 0" />
      <mass value="0.050000" />
      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
    </inertial>
    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
  </link>
  <link name="rh_upper_leg_link">
    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
    <inertial>
      <origin xyz="0.00108 -0.00015 -0.04503" rpy="0 0 0" />
      <mass value="0.172500" />
      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
    </inertial>
    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
  </link>
  <link name="rh_lower_leg_link">
    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
    <inertial>
      <origin xyz="0.03075 0.00118 -0.01958" rpy="0 0 0" />
      <mass value="0.059500" />
      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
    </inertial>
    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
  </link>
  <link name="rh_foot_link">
    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
    <inertial>
      <origin xyz="-0.00052 0 0.01548" rpy="0 0 0" />
      <mass value="0.017500" />
      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
    </inertial>
    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
  </link>
  <link name="lh_hip_link">
    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
    <inertial>
      <origin xyz="0.00366 0.02982 0.00694" rpy="0 0 0" />
      <mass value="0.050000" />
      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
    </inertial>
    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
  </link>
  <link name="lh_upper_leg_link">
    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
    <inertial>
      <origin xyz="0.00108 0.00015 -0.04503" rpy="0 0 0" />
      <mass value="0.172500" />
      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
    </inertial>
    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
  </link>
  <link name="lh_lower_leg_link">
    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
    <inertial>
      <origin xyz="0.03075 -0.00118 -0.01958" rpy="0 0 0" />
      <mass value="0.059500" />
      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
    </inertial>
    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
  </link>
  <link name="lh_foot_link">
    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
    <inertial>
      <origin xyz="-0.00052 0 0.01548" rpy="0 0 0" />
      <mass value="0.017500" />
      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
    </inertial>
    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
  </link>
  <joint name="lf_hip_joint" type="revolute">
    <parent link="base_link" />
    <child link="lf_hip_link" />
    <origin xyz="0.1125 0.0475 0.0465" rpy="0 0 0" />
    <axis xyz="1 0 0" />
    <limit lower="-0.785398163397" upper="0.785398163397" effort="0.902244" velocity="3.03687289847" />
    <dynamics damping="0" friction="0" />
    <hardware>
      <motorType>Feetech ST3215</motorType>
      <motorId>13</motorId>
      <motorDirection>1</motorDirection>
      <armature>0</armature>
    </hardware>
  </joint>
  <joint name="lf_upper_leg_joint" type="revolute">
    <parent link="lf_hip_link" />
    <child link="lf_upper_leg_link" />
    <origin xyz="0 0.048 0" rpy="0 0 0" />
    <axis xyz="0 1 0" />
    <limit lower="-0.916297857297" upper="2.138028333693" effort="0.902244" velocity="3.03687289847" />
    <dynamics damping="0" friction="0" />
    <hardware>
      <motorType>Feetech ST3215</motorType>
      <motorId>12</motorId>
      <motorDirection>1</motorDirection>
      <armature>0</armature>
    </hardware>
  </joint>
  <joint name="lf_lower_leg_joint" type="revolute">
    <parent link="lf_upper_leg_link" />
    <child link="lf_lower_leg_link" />
    <origin xyz="0 0 -0.09" rpy="0 0 0" />
    <axis xyz="0 1 0" />
    <limit lower="-1.605702911835" upper="0.654498469498" effort="0.902244" velocity="3.03687289847" />
    <dynamics damping="0" friction="0" />
    <hardware>
      <motorType>Feetech ST3215</motorType>
      <motorId>11</motorId>
      <motorDirection>1</motorDirection>
      <armature>0</armature>
    </hardware>
  </joint>
  <joint name="lf_foot_joint" type="fixed">
    <parent link="lf_lower_leg_link" />
    <child link="lf_foot_link" />
    <origin xyz="0.107 -0.0015 -0.0499" rpy="0 0 0" />
  </joint>
  <joint name="rf_hip_joint" type="revolute">
    <parent link="base_link" />
    <child link="rf_hip_link" />
    <origin xyz="0.1125 -0.0475 0.0465" rpy="0 0 0" />
    <axis xyz="1 0 0" />
    <limit lower="-0.785398163397" upper="0.785398163397" effort="0.902244" velocity="3.03687289847" />
    <dynamics damping="0" friction="0" />
    <hardware>
      <motorType>Feetech ST3215</motorType>
      <motorId>23</motorId>
      <motorDirection>1</motorDirection>
      <armature>0</armature>
    </hardware>
  </joint>
  <joint name="rf_upper_leg_joint" type="revolute">
    <parent link="rf_hip_link" />
    <child link="rf_upper_leg_link" />
    <origin xyz="0 -0.048 0" rpy="0 0 0" />
    <axis xyz="0 1 0" />
    <limit lower="-0.916297857297" upper="2.138028333693" effort="0.902244" velocity="3.03687289847" />
    <dynamics damping="0" friction="0" />
    <hardware>
      <motorType>Feetech ST3215</motorType>
      <motorId>22</motorId>
      <motorDirection>-1</motorDirection>
      <armature>0</armature>
    </hardware>
  </joint>
  <joint name="rf_lower_leg_joint" type="revolute">
    <parent link="rf_upper_leg_link" />
    <child link="rf_lower_leg_link" />
    <origin xyz="0 0 -0.09" rpy="0 0 0" />
    <axis xyz="0 1 0" />
    <limit lower="-1.605702911835" upper="0.654498469498" effort="0.902244" velocity="3.03687289847" />
    <dynamics damping="0" friction="0" />
    <hardware>
      <motorType>Feetech ST3215</motorType>
      <motorId>21</motorId>
      <motorDirection>-1</motorDirection>
      <armature>0</armature>
    </hardware>
  </joint>
  <joint name="rf_foot_joint" type="fixed">
    <parent link="rf_lower_leg_link" />
    <child link="rf_foot_link" />
    <origin xyz="0.107 0.0015 -0.0499" rpy="0 0 0" />
  </joint>
  <joint name="rh_hip_joint" type="revolute">
    <parent link="base_link" />
    <child link="rh_hip_link" />
    <origin xyz="-0.1125 -0.0475 0.0265" rpy="0 0 0" />
    <axis xyz="1 0 0" />
    <limit lower="-0.785398163397" upper="0.785398163397" effort="0.902244" velocity="3.03687289847" />
    <dynamics damping="0" friction="0" />
    <hardware>
      <motorType>Feetech ST3215</motorType>
      <motorId>33</motorId>
      <motorDirection>-1</motorDirection>
      <armature>0</armature>
    </hardware>
  </joint>
  <joint name="rh_upper_leg_joint" type="revolute">
    <parent link="rh_hip_link" />
    <child link="rh_upper_leg_link" />
    <origin xyz="0 -0.048 0" rpy="0 0 0" />
    <axis xyz="0 1 0" />
    <limit lower="-0.916297857297" upper="2.138028333693" effort="0.902244" velocity="3.03687289847" />
    <dynamics damping="0" friction="0" />
    <hardware>
      <motorType>Feetech ST3215</motorType>
      <motorId>32</motorId>
      <motorDirection>-1</motorDirection>
      <armature>0</armature>
    </hardware>
  </joint>
  <joint name="rh_lower_leg_joint" type="revolute">
    <parent link="rh_upper_leg_link" />
    <child link="rh_lower_leg_link" />
    <origin xyz="0 0 -0.09" rpy="0 0 0" />
    <axis xyz="0 1 0" />
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

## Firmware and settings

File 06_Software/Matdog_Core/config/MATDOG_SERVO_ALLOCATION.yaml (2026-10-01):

# MATDOG servo allocation — final 17 units

# Derived from the 2026-08-27 ST3215 provisioning campaign.
# Authoritative evidence: 09_Logs/Validation_Reports/ST3215_Provisioning_2026-08-27/

schema_version: 1
allocated_at: "2026-08-27"
total_units: 17
profile: MATDOG_C018_V1

# WARNING: this table maps PHYSICAL UNIT -> JOINT -> BUS ID.
# It says nothing about joint ZERO or LIMITS. All calibration is RESET as of 2026-08-27;
# see 09_Logs/Calibration/MATDOG_CALIBRATION_RESET_2026-08-27.md
#
# encoder_direction (12 leg joints only) - CURRENT-INSTALLATION encoder polarity,
# the ONLY authority for raw <-> URDF q:  raw = q0 + encoder_direction * ticks(q).
# Added 2026-10-01 after the TRUE LF Full Calibration drove LF LOWER into its
# short-side end-stop: the URDF custom <motorDirection> (+1) had been promoted
# (CR0, 2026-09-27) to hardware encoder polarity, which it never was. The URDF
# value stays design/spec metadata and must not drive hardware calibration.
#   encoder_direction_source:
#     CURRENT_HARDWARE_WITNESS   observed on THIS installation after 2026-08-27
#     HISTORICAL_SLOT_UNCHANGED  the joint SLOT's PASS_DIRECTION_TEST (2026-07-02/05),
#                                carried because every sign-defining property of the
#                                slot is unchanged: URDF joint axis/origin identical since
#                                2026-07-01, same ST3215-C018 MATDOG_C018_V1 servo type,
#                                same bracket/linkage design (the 2026-08-27 rebuild
#                                remounted units in the same slots' mechanics). Today's
#                                LF witnesses reproduced all three LF slot signs on
#                                re-slotted/new units (M22, ELR01, M33), so the sign
#                                follows the SLOT, not the unit.
# Full audit: 09_Logs/Development_Log/2026-09-30_TRUE_24_CONTACT_FULL_CALIBRATION.md §8d.

units:
  - unit: M22
    joint: LF_HIP
    bus_id: 13
    source_id: 22
    id_recode: RECODED
    position_offset: 0
    center_physical_raw: 2048
    center_error_ticks: 0
    cold_verify: PASS
    provisioner_firmware: V5
    session: M22__20260827_134852Z
    encoder_direction: -1
    encoder_direction_source: CURRENT_HARDWARE_WITNESS
    encoder_direction_evidence: "2026-10-01 read-only hand witness, torque off: URDF +q (foot outward) moved bus 13 raw 1992 -> 1713 (-279, 10+10 reads, spread 0)"
  - unit: ELR01
    joint: LF_UPPER
    bus_id: 12
    source_id: 6
    id_recode: RECODED
    position_offset: 0
    center_physical_raw: 2048
    center_error_ticks: 0
    cold_verify: PASS
    provisioner_firmware: V6
    session: ELR01__20260827_140449Z
    encoder_direction: 1
    encoder_direction_source: CURRENT_HARDWARE_WITNESS
    encoder_direction_evidence: "2026-10-01 TRUE LF run: UPPER MIN/MAX contacts 1465/3478 at q0 2078 = -53.9/+122.9 deg, the asymmetric URDF range only under +1"
  - unit: M33
    joint: LF_LOWER
    bus_id: 11
    source_id: 33
    id_recode: RECODED
    position_offset: 0
    center_physical_raw: 2049
    center_error_ticks: 1
    cold_verify: PASS
    provisioner_firmware: V6
    session: M33__20260827_140704Z
    encoder_direction: -1
    encoder_direction_source: CURRENT_HARDWARE_WITNESS
    encoder_direction_evidence: "2026-10-01 operator witness: under +1 'LOWER MIN' drove the shank BACKWARD into the short-side end-stop, raw ~1690 = 35.0 deg from q0 2088 (URDF MAX +37.5)"
  - unit: NEW01
    joint: RF_HIP
    bus_id: 23
    source_id: 1
    id_recode: RECODED
    position_offset: 0
    center_physical_raw: 2047
    center_error_ticks: -1
    cold_verify: PASS
    provisioner_firmware: V4
    session: NEW01__20260827_122920Z
    encoder_direction: -1
    encoder_direction_source: HISTORICAL_SLOT_UNCHANGED
    encoder_direction_evidence: "09_Logs/Calibration_Sessions/2026-07-05_154026_m23_rf_hip_negative_probe.result.yaml"
  - unit: ELR03
    joint: RF_UPPER
    bus_id: 22
    source_id: 7
    id_recode: RECODED
    position_offset: 0
    center_physical_raw: 2049
    center_error_ticks: 1
    cold_verify: PASS
    provisioner_firmware: V5
    session: ELR03__20260827_130419Z
    encoder_direction: -1
    encoder_direction_source: HISTORICAL_SLOT_UNCHANGED
    encoder_direction_evidence: "09_Logs/Calibration_Sessions/2026-07-05_154229_m22_rf_upper_positive_probe.result.yaml"
  - unit: NEW03
    joint: RF_LOWER
    bus_id: 21
    source_id: 1
    id_recode: RECODED
    position_offset: 0
    center_physical_raw: 2048
    center_error_ticks: 0
    cold_verify: PASS
    provisioner_firmware: V5
    session: NEW03__20260827_131754Z
    encoder_direction: 1
    encoder_direction_source: HISTORICAL_SLOT_UNCHANGED
    encoder_direction_evidence: "09_Logs/Calibration_Sessions/2026-07-05_154451_m21_rf_lower_negative_probe.result.yaml"
  - unit: NEW06
    joint: RH_HIP
    bus_id: 33
    source_id: 1
    id_recode: RECODED
    position_offset: 0
    center_physical_raw: 2047
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

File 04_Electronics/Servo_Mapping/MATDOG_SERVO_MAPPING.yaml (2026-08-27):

schema_version: 1
robot_id: MATDOG
status: UNCALIBRATED

servo_model: ST3215

transport:
  current_backend: ESP32-S3 motion coprocessor (USB CDC host link) + Seeed Bus Servo Driver
  historical_backend: NormaCore Station + Waveshare Bus Servo Adapter  # superseded 2026-08-27
  authoritative_allocation: 06_Software/Matdog_Core/config/MATDOG_SERVO_ALLOCATION.yaml
  note: >
    This file records the historical 12-servo mapping. The robot now has 17 servos and 14 of them
    were recoded to new bus IDs on 2026-08-27. Use MATDOG_SERVO_ALLOCATION.yaml as the current
    unit -> joint -> bus ID source.
  future_backend: ESP32 motion controller
  raw_servo_protocol_owner: NormaCore ST3215 driver

control_contract:
  dashboard_command_unit: rad
  controller_command_unit: rad
  actuator_target_unit: encoder_ticks
  raw_encoder_range: [0, 4095]

legs:
  LF:
    display_name: Front Left
    joints:
      hip:
        joint_name: lf_hip_joint
        servo_id: 13
        direction: null
        zero_encoder: null
        min_rad: null
        max_rad: null
      upper:
        joint_name: lf_upper_leg_joint
        servo_id: 12
        direction: null
        zero_encoder: null
        min_rad: null
        max_rad: null
      lower:
        joint_name: lf_lower_leg_joint
        servo_id: 11
        direction: null
        zero_encoder: null
        min_rad: null
        max_rad: null

  RF:
    display_name: Front Right
    joints:
      hip:
        joint_name: rf_hip_joint
        servo_id: 23
        direction: null
        zero_encoder: null
        min_rad: null
        max_rad: null
      upper:
        joint_name: rf_upper_leg_joint
        servo_id: 22
        direction: null
        zero_encoder: null
        min_rad: null
        max_rad: null
      lower:
        joint_name: rf_lower_leg_joint
        servo_id: 21
        direction: null
        zero_encoder: null
        min_rad: null
        max_rad: null

  RH:
    display_name: Rear Right
    joints:
      hip:
        joint_name: rh_hip_joint
        servo_id: 33
        direction: null
        zero_encoder: null
        min_rad: null
        max_rad: null
      upper:
        joint_name: rh_upper_leg_joint
        servo_id: 32
        direction: null
        zero_encoder: null
        min_rad: null
        max_rad: null
      lower:
        joint_name: rh_lower_leg_joint
        servo_id: 31
        direction: null
        zero_encoder: null
        min_rad: null
        max_rad: null

  LH:
    display_name: Rear Left
    joints:
      hip:
        joint_name: lh_hip_joint
        servo_id: 43
        direction: null
        zero_encoder: null
        min_rad: null
        max_rad: null
      upper:
        joint_name: lh_upper_leg_joint
        servo_id: 42
        direction: null
        zero_encoder: null
        min_rad: null
        max_rad: null
      lower:
        joint_name: lh_lower_leg_joint
        servo_id: 41
        direction: null
        zero_encoder: null
        min_rad: null
        max_rad: null

calibration_rules:
  - Do not use Station generic Calibrate for MATDOG kinematic calibration.
  - Record encoder zero only in the approved mechanical zero pose.
  - Determine direction with one joint at a time and low-energy movement.
  - Determine software limits from measured mechanical limits.
  - Update this file only after a documented validation test.

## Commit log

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2026-07-01 fix(urdf): declare STL millimetre mesh scale
    [Coordinate_Cinematiche_matt_robodog_rev00.xlsx, matt_robodog_rev00.urdf]
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2026-07-03 fix(matdog): sync lower-leg limits and calibration references
    [MATDOG_JOINT_CALIBRATION.yaml, matt_robodog_rev00.urdf]
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2026-07-07 calib: unify static tracking tolerance at 10 ticks
    [MATDOG_JOINT_CALIBRATION.yaml]
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2026-07-21 calib: tolerate missing Station last command state
    [matdog_endstop_station_telemetry.py]
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2026-07-31 fix(milestone-i): enforce canonical foundation invariants
    [calibration_registry.csv, frame_registry.csv, joint_registry.csv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]
2026-07-31 fix(milestone-i): bind foundation validation to pinned git blobs
    [source_claim_registry.csv]
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2026-08-04 docs(calib): close LF V25 milestone and clean project status
    Publish the validated LF V25 calibration result, replace the stale project status, and record the cross-repository cleanup policy.
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2026-08-09 feat(calib): complete adjacent endstop metrology Phase 1B (#16)
    Joint-aware adjacency: 12 REVOLUTE adjacent pairs included, 4 FIXED excluded.
    ENDSTOP METROLOGY = active revolute parent-child pair; PATH SAFETY = all other
    relevant pairs, active pair excluded from its own sweep. Generic 3 mm clearance
    gate stays NON_ADJACENT-only; boolean intersection separated from near-miss
    clearance. Five canonical collision STLs corrected for motor-pin representation;
    URDF byte-identical, rev00 unchanged.
    GATE A PASS, GATE B SUPPORTED. Compiler 24/24 exit 0. Full suite 122/122 exit 0.
    21 MODELED_ENDSTOP_CONTACT / 3 MODEL_INCOMPLETE / 0 NO_MODELED_ENDSTOP. Historical
    path regressions -47.5000 deg and -97.9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
    [base_link.stl, lf_upper_leg_link.stl, lh_upper_leg_link.stl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]
2026-08-09 docs(calib): close Phase 1B and hand off Phase 2 (#17)
    Documentation only. Phase 1B addendum status -> CLOSED/merged (PR #16,
    5b66044e225fcd921e44b98cc710f028da441a64); README current-state -> VALIDATED AND MERGED plus
    Phase 2 entry plan; verification index records the closure state. Adds the durable handoff
    MATDOG_CALIBRATION_CANONICAL_HANDOFF_PHASE1B_CLOSED_2026-08-09.md.
    Open items unchanged: three LF endpoints HARDWARE_CONTRADICTED (cause UNKNOWN); RF/RH/LH
    GEOMETRIC_ENDPOINT_CANDIDATE; adjacent sensitivity NOT_APPLICABLE; assembly tolerance
    unmodelled; parking REVALIDATED / UNCHANGED FROM v3 (passed=False 4/4), not a PASS.
    Phase 1B CLOSED. Phase 2 NEXT. Phase 2 NOT STARTED.
2026-08-09 docs(calib): make Phase 1B handoff provenance non-self-referential (#18)
    Documentation only. Handoff provenance now recorded as immutable merge points
    (PR #16 -> 5b66044e..., PR #17 -> 2363b2a4...) with the canonical HEAD resolved from origin/main
    and deliberately NOT self-pinned, since a tracked document cannot pin the HEAD of the history
    containing it. Verification index now names the 2026-08-09 Phase-1B-closed handoff as the current
    Phase 2 entry point; the 2026-08-07 handoff is retained as an architectural/historical reference,
    not deleted.
    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
2026-08-11 Geometry Compiler V5: deterministic pure geometry pipeline (#19)
    Merge the independently audited and remediated MATDOG Geometry Compiler V5 / Phase 2A0 foundation. Canonical q=0 V5 is separated from non-canonical G4 replay; corrected C/D deterministic artifacts, G12 reconciler/safety outputs and final offline validation are included. Phase 2A0 closure authorized explicitly by Matteo.
    [MATDOG_JOINT_CALIBRATION.yaml, base_link.stl, lf_foot_link.stl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]
2026-08-27 feat(firmware): archive frozen ST3215 bench tools (QC V6.1, Survey V1, Provisioner V6)
    Archive the three ESP32-S3 bench tools byte-for-byte, with SHA256 manifests,
    command surfaces, toolchain/FQBN, test results and explicit validation scope.
    Bench QC V6.1 matdog_servo_commissioning.ino 74656fb9...
    Source Survey V1 matdog_st3215_source_survey_v1 f37fa85a...
    Provisioner V6 matdog_st3215_provisioner_v1 680b2715...
    Documentation correction: the QC V6.1 binary was previously described as
    EEPROM-write-incapable. That is wrong. It contains @NORMALIZE_MATDOG <id> ->
    runNormalizeMatdog() with five real EEPROM writes. The campaign runner never
    invoked it - the command is absent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
    [matdog_qc_runner.py, matdog_servo_commissioning.ino, matdog_st3215_source_survey_v1.ino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]
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2026-08-27 docs(provisioning): archive 17/17 ST3215 campaign and final servo allocation
    All 22 session directories (17 authoritative finals + 5 retries), persistence
    audits, characterization sessions and read-only survey evidence, plus the
    authoritative unit -> joint -> bus ID allocation for all 17 servos.
    Acceptance contract re-verified from the committed reports, not from summaries:
    17/17 PASS, model 777, PositionOffset 0, centre 2048 +/-1 (observed 2047..2049),
    Lock 1, torque OFF, cold PASS, target ID reached, old ID silent on all 14
    recodes, TorqueLimit 1000 after cold, single profile fingerprint on all 17.
    Two corrections to the received narrative:
    1. PROFILE EEPROM WRITE IS NOT HARDWARE VALIDA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
    [MATDOG_SERVO_ALLOCATION.yaml, all_sessions_index.tsv, final_session_index.tsv]
2026-08-27 docs(calib): declare full calibration RESET after 17-servo reassembly
    All 17 servos were removed, bench-provisioned to PositionOffset = 0 and are
    being remounted. Every joint zero, direction and limit on record describes an
    installation that no longer exists.
    - old digital zero / q0 are HISTORICAL EVIDENCE, not active truth
    - LF V25 remains an oracle and history, not proof of the new installation
    - Geometry Compiler / CAD geometry is unaffected and stays valid
    - PositionOffset = 0 is the baseline and must remain so
    - CalibrationOfs, one-key-middle and compensating mechanics by rewriting
    PositionOffset are forbidden
    - q0 correction must be MEASURED, not asserted to zero
    - no hardware motio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
    [MATDOG_JOINT_CALIBRATION.yaml]
2026-08-27 docs: update README and add ST3215 evidence index and handoff
    Root README brought in line with the verified current state:
    - MATDOG is now a 17-servo robot (12 leg + 5 head/jaw), not 12
    - prominent CALIBRATION RESET REQUIRED banner
    - current-state table rewritten: QC complete, profile frozen, 17/17 provisioned,
    reassembly in progress, calibration reset, head joints never calibrated
    - the stale 12-servo mapping block is replaced by the verified allocation, with
    a warning that 14 units were recoded so historical bus-ID records will
    associate the wrong joint
    - LF V25 marked historical oracle; frozen LF offsets noted as no longer present
    - next milestone corrected to reassembly -> full rec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
2026-08-27 docs(arch): supersede the Station-owned model with ESP32-S3 bus ownership
    MATDOG no longer presents NormaCore Station as the required or permanent owner of
    the ST3215 servo bus.
    New canonical architecture:
    high-level host (ASUS now, Jetson-class later; ROS 2 / MoveIt 2 intended)
    -> dedicated MATDOG ESP32-S3 coprocessor = operational owner of the bus
    -> 17 x Feetech ST-3215-C018 (12 leg + 5 head/jaw)
    Station is now optional/legacy/reference: valid as historical technology and as an
    optional telemetry/observation/logging component, but NOT a mandatory ST3215 owner,
    NOT a required calibration or provisioning path, and NOT the definitive control
    architecture. This is not a ban on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
2026-08-27 feat(calib): machine-enforced fail-closed gate for stale calibration
    Resolves the contradiction where docs said full recalibration was required but
    code could still act on the old calibration.
    Per-consumer audit found the consumers do NOT assert a common enum. They assert
    five different values across a legacy state machine:
    matdog_capture_visual_zero.py DIRECTION_MAPPING_COMPLETE_ZERO_PENDING
    matdog_apply_visual_zero.py DIRECTION_MAPPING_COMPLETE_ZERO_PENDING -> VISUAL_ZERO_...
    matdog_visual_zero_pose_probe.py VISUAL_ZERO_CAPTURED_PENDING_LIVE_VALIDATION
    matdog_live_joint_monitor.py VISUAL_ZERO_CAPTURED_PENDING_LIVE_VALIDATION
    matdog_leg_fk_live.py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
    [matdog_endstop_station_readonly_watch.py]
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2026-08-27 docs(arch): freeze host transport, servo driver, compute split and onboard host
    Precision pass aligning the repository with the frozen hardware decisions.
    HOST TRANSPORT IS NO LONGER TBD.
    Native USB 2.0 Full-Speed / USB CDC is the primary host<->coprocessor link, in
    development (ASUS Ubuntu) and in the final onboard configuration (Jetson Orin
    Nano Super). ESP32-S3 native USB: D- = GPIO19, D+ = GPIO20, 12 Mbit/s
    theoretical; USB 3.x is neither required nor available on ESP32-S3. Wi-Fi remains
    a planned secondary command/diagnostic channel.
    Physical transport and protocol are now stated separately: the transport is
    frozen and already in use, the packet/command/telemetry protocol carried over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
    [MATDOG_SERVO_MAPPING.yaml]
2026-08-27 docs(electronics): stop implying the 17-servo power system is validated
    The Power section said "The custom distribution board and branch wiring are
    validated for the locomotion-development phase". That validation belongs to the
    12-servo Station-mediated configuration, which the robot no longer has, and read
    as though the current 17-servo power architecture were hardware-validated.
    Split into explicit scopes:
    VALIDATED (real hardware): ESP32-S3 direct ST3215 bus operation; the direct
    bus-control path to the extent covered by real bring-up evidence; QC and
    provisioning (26 runs, 17/17 units). Qualified as BENCH evidence - single-unit
    rig, one servo at a time - which says nothing about the as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
2026-09-15 docs(controller): freeze V0.1 source provenance
    Audit table of every candidate standalone source under
    ~/MATDOG/runtime/esp32 considered for the unified MATDOG Controller
    V0.1 runtime: absolute path, size, mtime, SHA256, role and hardware
    validation status. Resolves two ambiguities found during the audit
    that the handoff did not anticipate: matdog_daly_rs485_probe_v2.ino
    (not v1) is the CRC-validated decoder that actually produced the
    handoff's cited telemetry, and both DALY probes collide with the
    ST3215 transport on HardwareSerial(1).
    No standalone source was modified.
2026-09-15 feat(controller): add modular ESP32-S3 runtime scaffold
    Thin .ino entry point (setup/loop only) plus the core/config layer:
    - Pins.h: single canonical GPIO ownership map for every module.
    - BuildConfig.h: firmware identity, bench test profile (USB_ONLY),
    bus bauds, build-id injection point.
    - SystemState: per-module + aggregated system health.
    - PowerState: OFF -> KEY ON -> BOOT -> CHECK -> RUN -> SHUTDOWN
    baseline. Shutdown always resolves to POWER_CUT_FAILED in V0.1
    because the DALY Discharge-MOS-OFF write protocol is not yet
    verified (handoff 8A.8) - no frame is ever transmitted.
    - CommandRouter: small explicit USB diagnostic command surface
    (@HELP/@STATUS/@IMU/@BMS/@LED/@SERVO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
    [BuildConfig.h]
2026-09-15 feat(controller): integrate ST3215 servo bus transport
    ServoBus adapts the hardware-proven transport from the frozen Bench
    QC V6.1 commissioning source (SHA256 74656fb9...d25630cd): GPIO17/18,
    1 Mbps, SCServo/SMS_STS, no automatic ping/scan/torque on boot.
    Read-only diagnostics only: ping, model-word read (register 0x03),
    bounded ID-range scan, runtime-state read. The only write is
    EnableTorque(id, 0) behind @SERVO SAFE_OFF - it can remove torque,
    never enable it, and never touches EEPROM. Not imported: EEPROM
    normalization, ID recode, CalibrationOfs, factory reset, broadcast
    write, and every GoalPosition/motion primitive - none of that
    transport exists in this module at all.
2026-09-15 feat(controller): integrate BNO085 IMU acquisition
    Bno085Imu adapts matdog_bno085_dcd_phase_c3.ino (SHA256 51bb3016...
    cccd103e6), the source the existing full-body viewer is validated
    against. Preserves the pin map, SPI init sequence, SH2_ROTATION_VECTOR
    as the orientation source, sh2_setDcdAutoSave(false), and - byte for
    byte - the RV/MAG/GYR/COUNTS/SAVE_GATE/UNEXPECTED_RUNTIME_RESET text
    protocol the viewer's lineParser.ts expects, on the same ~500 ms
    cadence.
    Deliberately not imported: the "SAVE" serial command and its
    sh2_saveDcdNow() call - no code path to it exists anywhere in this
    firmware. Deliberately different: the original halts forever
    (fatal()) on any SPI/session-config failur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
2026-09-15 feat(controller): integrate DALY BMS telemetry
    DalyBms adapts matdog_daly_rs485_probe_v2.ino (SHA256 4fd7fd39...
    7756acb81c), the CRC-validated decoder that produced the handoff's
    cited telemetry (V1 only dumps raw hex). Preserves GPIO15/16, 9600
    8N1, the exact 8-byte Modbus read query and the full register decode
    map (cells/temps/pack V/I/SOC/MOS/alarms).
    Two deliberate differences from both probes:
    - Non-blocking poll state machine instead of a 750 ms busy-wait
    inside loop() - that would stall BNO085 acquisition and the USB
    command router for the same window every ~2 s.
    - Bound to HardwareSerial(2), not (1): both standalone probes share
    HardwareSerial(1) with the ST3215 transport,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
2026-09-15 feat(controller): add LED ring module
    No prior MATDOG LED/ring/WS2812 source exists anywhere under
    ~/MATDOG/runtime/esp32 (confirmed by a targeted audit grep) - this is
    the one genuinely new low-level module in V0.1, as the handoff
    anticipated. Built on Adafruit NeoPixel 1.15.5 (installed for this
    task; no hand-rolled WS2812 timing/RMT code) rather than reinvented.
    Boots OFF, brightness capped well under hardware maximum even for the
    diagnostic test pattern, every effect driven by a non-blocking
    update() state machine. A failure here cannot stop the rest of the
    controller - there is no path in this module that can loop or block.
2026-09-15 test(controller): add build script and static safety audit
    scripts/build.sh wraps arduino-cli compile with the pinned FQBN and
    injects a build id (short git SHA, -dirty suffix if uncommitted) that
    shows up in the boot banner and @STATUS. scripts/upload.sh performs a
    normal Arduino application upload (no flash erase, no bootloader/
    partition/NVS touch beyond the standard Arduino OTA data partition).
    scripts/static_audit.py is a regression tripwire, not a formal
    verifier: fails the build on CalibrationOfs, EEPROM ID/offset writes,
    non-zero EnableTorque, any GoalPosition reference, automatic BNO085
    DCD save, a DALY write path that isn't the fail-closed placeholder,
    duplicate GPIO ownership, or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
2026-09-15 docs(controller): record V0.1 validation scope
    README/CHANGELOG for MATDOG_Controller, and VALIDATION.md recording
    the full USB-only bench session against real hardware (build id
    03992a473bba, base commit 03992a473bba9220f32172ac57ac5d860f3d1462):
    - U1 boot: PASS - correct banner, no motion/torque on boot, zero
    unexpected resets.
    - U2 BNO085 live: PASS - RV/MAG reach full calibration within ~5s,
    SAVE_GATE interlock behaves identically to the standalone firmware,
    59/59 existing viewer tests pass unmodified.
    - U3 expected-offline: PASS - DALY/ST3215/LED all classify as
    OFFLINE_EXPECTED (not fault) in the exact PROFILE=/EXPECTED=/
    CLASSIFICATION= shape the handoff specified.
    - U4 soa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
2026-09-15 fix(controller): separate initialized/detected/expected/result semantics
    Session 1 conflated "software driver initialized" with "hardware
    physically online": ServoBus::begin() set ModuleHealth::OK
    unconditionally, so @STATUS reported servo=OK even with zero servos
    powered. Introduces core::Availability (InitializationState /
    DetectedState / ExpectedState -> Classification) so those four
    questions are answered separately and classify() is the single place
    profile-dependent judgement happens.
    A future ROBOT_POWERED profile changes a module's ExpectedState (e.g.
    DALY REQUIRED instead of EXPECTED_OFFLINE) and the same classify()
    turns an unchanged NO_RESPONSE into FAULT/DEGRADED automatically -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
    [BuildConfig.h]
2026-09-15 fix(controller): stop driving the LED ring rail under USB_ONLY
    Session 1's LedRing::begin() called pixels_.begin()/show() and
    @LED TEST transmitted real WS2812 frames even though the 5V rail
    feeding the ring is physically absent in USB_ONLY - back-powering an
    unpowered peripheral through the data line, which the handoff's
    anti-back-power rule (7A.4) exists specifically to prevent.
    When build::kLedRailPowered is false (current profile): begin() only
    sets GPIO47 to INPUT (a defined, conservative, high-impedance state,
    not left floating) and never calls into Adafruit_NeoPixel at all;
    startTest() refuses and returns false instead of running the chase;
    off()/setSolid() are no-ops. GPIO47 is neve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
2026-09-15 fix(controller): make servo bus scan non-blocking
    Session 1's scan(lo, hi) pinged an entire ID range synchronously
    inside one call. Each Ping() carries the SCServo library's own
    ~100ms IOTimeOut, so scanning the full 11-55 allocation range with
    nothing responding (exactly the USB_ONLY case) could monopolize
    loop() for ~4.5s - starving BNO085 acquisition and the USB command
    router for the whole scan, and incompatible with the stated principle
    that no module may monopolize loop().
    Replaces it with startScan()/update()/scanState(): a state machine
    that probes exactly one ID per update() tick and returns control to
    the caller immediately, bounding any single loop() iteration's servo-
    bus blocki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
2026-09-15 fix(controller): wire BNO085 and DALY into the availability model
    Bno085Imu: begin_SPI() already performs a real SHTP handshake with
    the physical chip, so a successful begin() is genuine hardware
    detection (DetectedState::ONLINE), not just "driver ready" - and
    ExpectedState is REQUIRED (3V3-powered, always expected reachable).
    An SPI.begin() failure is host-side (DetectedState::UNKNOWN); a
    begin_SPI()/calibration-session failure means the chip handshake
    itself failed (DetectedState::NO_RESPONSE).
    DalyBms: ExpectedState now derives from build::kBatteryAvailable
    (EXPECTED_OFFLINE under USB_ONLY) instead of being folded into a
    single ad-hoc ModuleHealth. TIMEOUT/BAD_HEADER/CRC_FAIL all map to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
2026-09-15 fix(controller): report init/detected/expected/result at @STATUS
    Controller::update() now calls servo_bus_.update(now_ms) every tick
    (previously never called - the async scan state machine from the
    prior commit would otherwise never advance). Boot banner additionally
    reports the currently running OTA partition
    (esp_ota_get_running_partition(): label/offset/size) alongside the
    existing build id, as a second independent provenance signal read
    directly from the running firmware.
    CommandRouter: @STATUS, @IMU STATUS, @BMS STATUS and @LED STATUS now
    print "<LABEL> init=.. detected=.. expected=.. result=.." for each
    module instead of a single ad-hoc health word, using
    core::Availability. @SERVO SC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
2026-09-18 fix(controller): make USB CDC TX non-blocking
    [BuildConfig.h]
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2026-09-21 feat(calibration): add the host-testable calibration domain model
    Recovered from the LF V25 hardware oracle rather than redesigned. Pure:
    no Arduino runtime, no ServoBus, no Wi-Fi, no OTA, no hardware call, so the
    offline suite links the real model - the same contract as WifiPolicy,
    OtaPolicy and ActuatorAuthority.
    Every concept is traceable to a source, and where the archive is silent the
    gap is represented rather than filled in. Three findings from the C0 audit
    are encoded directly in the types:
    - q0 is not a constant, and 2048 is THREE different quantities that happen
    to share a value: the ST3215 raw centre (a servo-level fact that "says
    nothing about joint zero, mounting or directi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
    [CalibrationDomain.cpp, CalibrationDomain.h]
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2026-09-22 feat(calibration): give the Controller the compiled V5 geometry
    Geometry Compiler V5 is reused, not rewritten. Its canonical bundle
    2026-08-11_131818_..._REMEDIATION_BENCHMARK_D_W4 was re-verified against the
    current repository and every input still hashes identically: the URDF, all 17
    collision meshes, the nine canonical compiler sources and the eight published
    artifacts. The bundle was generated from the geometry the robot has now, so it
    is REUSED rather than regenerated.
    matdog_calibration_geometry_export.py is a reduction, not a second geometry
    engine: it computes no collision, no forward kinematics and no contact search.
    It copies the bundle's numbers into integer micro-radians, re-ver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
    [matdog_calibration_geometry_export.py]
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2026-09-27 fix(calibration): reject anomalous formal population evidence
    [CalibrationDomain.cpp]
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2026-10-01 fix(calibration): encoder direction from the current-installation record, not the URDF
    Hardware finding, 2026-10-01. The TRUE LF run (build 418c4c2e6562, fresh
    q0, INITIAL RECOVERY 12/12) measured UPPER MIN/MAX, then failed closed in
    LOWER MIN with EARLY_STALL_OUTSIDE_CORRIDOR at raw 1690: under the URDF
    custom motorDirection (+1) "LOWER MIN" ran RAW DECREASING and the operator
    saw the shank strike its real SHORT-side (MAX) end-stop - 398 ticks = 35.0
    deg from q0 2088, the URDF MAX magnitude, not MIN's 92. SAFE_OFF 13/13,
    export 0/24, evidence only.
    Root cause (class A, wrong source data): CR0 (2026-09-27) made the URDF
    custom <motorDirection> the only direction authority, stating it was
    ha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
    [MATDOG_SERVO_ALLOCATION.yaml]
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2026-10-02 feat(firmware): MATDOG V1 flash layout with 5 MiB slots and flashing-safety gates
    Offline only. Adds partitions.csv (layout MATDOG_16M_2x5M_NVS_V1, default NVS
    before matdog_nvs at 0xFE0000), the pinned layout contract and its checks
    (matdog_layout.py), Manifest V2 binding the layout id / produced partition
    table hash / app slot size, installed-table and write-range gates in
    flash_app_only.sh, a refusing upload.sh, and an OTA refusal when the running
    partition table is not the compiled-in contract. No migration, flash, erase
    or device communication.
    [partitions.csv]
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2026-10-08 fix(boot): run one read-only servo census at ROBOT_POWERED startup (0.2.0-dev.2) (selective recreation)
    Original-SHA: bac652fe37705ecb5ecdd0521dc64db95926d47e
    Files recovered: static_audit.py, 4 host tests, BuildConfig.h, Controller.{cpp,h}, ServoBus.cpp, ServoCensus.h (10 files).
    Files modified relative to the original: none
    Files excluded: none.
    Reason for selective recreation: the original commit descends from 3f23439, which
    carries third-party XGO decompiler extracts that must not enter the history of main
    (ADR-004). The original SHA is NOT an ancestor of main; it stays preserved on
    backup/matdog-dev3-preservation-20261008 and integration/matdog-controller-v0.2.0.
    Boot self-test census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
    [BuildConfig.h]
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2026-10-08 fix(thermal): take the thermal verdict from direct reads only (0.2.0-dev.3) (selective recreation)
    Original-SHA: 62812cd66816b4b5506337bf7f3245ecce13a2ad
    Files recovered: ThermalConfirmation.{h,cpp}, Controller.cpp, BuildConfig.h, static_audit.py and 6 host/mutation tests (11 files).
    Thermal verdict on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
    [BuildConfig.h]
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
